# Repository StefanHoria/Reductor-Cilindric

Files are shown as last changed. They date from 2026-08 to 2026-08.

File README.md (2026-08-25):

# Single-Stage Helical Gear Reducer — RCil H

**Year project — Machine Elements (Organe de Mașini)**
Transilvania University of Brașov · Faculty of Mechanical Engineering
Department of Automotive and Transport Engineering · 2026

The complete design of a single-stage speed reducer with a helical cylindrical gear pair and a
horizontal shaft plane (the **RCil H** variant): from the design brief and the analytical
calculations, through 3D modelling in CATIA V5 and verification in MDESIGN, to the assembly drawing
and the detail drawings.

| | |
|---|---|
| **Author** | Horia-Eusebiu ȘTEFAN — Robotics programme, group 4LF832 |
| **Supervisors** | Prof. dr. eng. Gheorghe MOGAN · Dr. eng. Eugen BUTILĂ · Eng. Diana BUZDUGAN |
| **Software** | CATIA V5 (3D modelling, drawings), MDESIGN 2020 (shaft verification) |
| **Documentation** | [Technical report (PDF, 47 pages, Romanian)](docs/Memoriu-Tehnic-Stefan-Horia-Eusebiu.pdf) |

> 🇷🇴 Documentul în limba română: [README.ro.md](README.ro.md)

<p align="center">
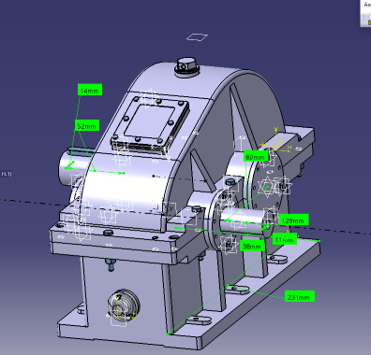
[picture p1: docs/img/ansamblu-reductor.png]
RCil H reducer — general assembly in CATIA V5
  
  <br>
  <sub><i>General assembly of the RCil H reducer on its test-bench frame, modelled in CATIA V5.</i></sub>
</p>

---

## 1. Design brief

| Parameter | Symbol | Value |
|---|---|---|
| Input power | `P_i` | 17.5 kW |
| Input speed | `n_i` | 3000 rpm |
| Transmission ratio | `i_R` | 3 |
| Required service life | `L_h imp` | 12,000 hours |
| Shaft plane | `PA` | Horizontal (H) |
| Number of pinion teeth | `z_1` | 19 |

**Operating conditions:** vehicle lift or brake test bench; alternating external load with shocks;
driven by a squirrel-cage asynchronous electric motor; noise level max. 25 dB; environment
−20…60 °C, humidity max. 30 g/m³.

**Construction constraints:** input and output on opposite sides, solid output shaft.

---

## 2. Kinetostatic parameters

| Shaft | Power | Speed | Torque |
|---|---|---|---|
| Input (A1) | `P_1` = 17.5 kW | `n_1` = 3000 rpm | `M_t1` = 55,704 Nmm |
| Output (A2) | `P_2` = 16.62 kW | `n_2` = 1000 rpm | `M_t2` = 158,756 Nmm |

Assumed gear efficiency: `η` = 0.95.
Tooth counts: `z_1` = 19, `z_2` = 57 → recalculated ratio `u` = 3, deviation from `i_R` = **0 %**.

---

## 3. The helical gear pair

<p align="center">
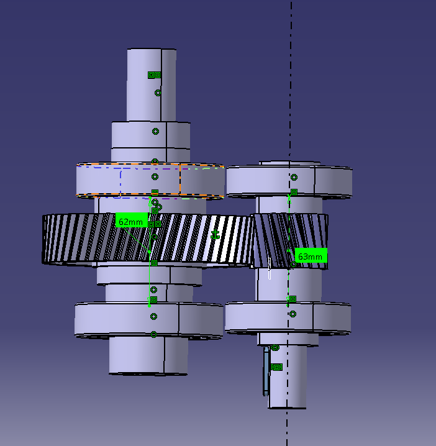
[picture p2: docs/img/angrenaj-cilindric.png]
Helical gear pair in mesh
  
  <br>
  <sub><i>The gear pair in mesh: pinion <code>z<sub>1</sub></code> = 19 and wheel <code>z<sub>2</sub></code> = 57,
  helix angle &beta; = 14&deg;, centre distance <code>a<sub>w</sub></code> = 80 mm.</i></sub>
</p>

### Material and heat treatment

Since `M_t1` = 55,704 Nmm > 30,000…40,000 Nmm, a **case-hardening steel, 20TiMnCr12**, was adopted
for both wheels.

| `σ_c` | `σ_r` | Treatment | Flank hardness | Core hardness | `σ_Hlim` | `σ_Flim` |
|---|---|---|---|---|---|---|
| 850 MPa | 1100 MPa | Carburising | 60 HRC | 340 HB | 1530 MPa | 430 MPa |

Manufacturing: milling before carburising, grinding after quenching and tempering.

### Preliminary sizing and geometry

Calculated transverse module: `m_c` = max(`m_H`, `m_F`) = max(1.89 ; 1.82) = **1.89 mm** → contact
stress is the governing criterion.

| Parameter | Relation | Value |
|---|---|---|
| Normal module (standardised) | `m_n` | 2 mm |
| Transverse module | `m = m_n / cos β` | 1.889 mm |
| Helix angle | `β` | 14° |
| Pinion reference diameter | `d_1 = m·z_1` | 35.9 mm |
| Wheel reference diameter | `d_2 = m·z_2` | 107.673 mm |
| Reference centre distance | `a` | 78.32 mm |
| **Standardised centre distance** | `a_w` | **80 mm** |
| Wheel face width | `b_2` | 27 mm |
| Pinion face width | `b_1 = b_2 + 4…6` | 31 mm |

Standardisation constraint `−0.5·m_n < a_w − a ≤ m_n` → `−1 < 1.68 ≤ 2` ✔

### Profile shift (PLUS gearing)

To achieve the required centre distance together with improved contact and bending strength:

| `x_n1` | `x_n2` | `x_ns` | `α` (transverse pressure) | `α_w` (transverse working) |
|---|---|---|---|---|
| +0.4711 | +0.4278 | 0.899 | 20.5617° | 23.561° |

Tooth tip thickness check (measured on the CATIA model):
`s_1` = 0.433 mm, `s_2` = 0.973 mm > (0.3…0.45)·`m_n`/2 ✔

### Contact continuity

Transverse contact ratio, obtained by measurement on the CATIA simulation model:
`ε_αm` = (T₁B − T₁A) / `p_b` = (12.884 − 4.589) / 6.043 = **1.372**
against the calculated value `ε_α` = **1.381** → deviation **−0.65 %** ✔

### Manufacturing and assembly

| | |
|---|---|
| Accuracy grade / fit | 8 / B, backlash tolerance type *b* |
| Final machining process | Careful milling and slotting |
| Surface roughness | flank `Ra` = 0.8 μm · root fillet `Ra` = 1.6 μm |
| Lubricant | TIN 300 EP transmission oil |
| Minimum normal backlash | `j_n min` = 87 μm |
| Radial runout tolerances | `F_r` = 45 μm (pinion) · 63 μm (wheel) |
| Span measurement | 19.85 ⁻⁰·¹ ⁻⁰·¹⁶ over 3 teeth (pinion) · 66.28 ⁻⁰·¹⁸ ⁻⁰·²⁸ over 9 teeth (wheel) |
| Centre distance limit deviations | `f_a` = ±70 μm |

### Gear mesh forces

| `F_t` (tangential) | `F_r` (radial) | `F_a` (axial) |
|---|---|---|
| 2785.2 N | 1213.94 N | 694.43 N |

---

## 4. Shafts, bearings and keys

<table>
<tr>
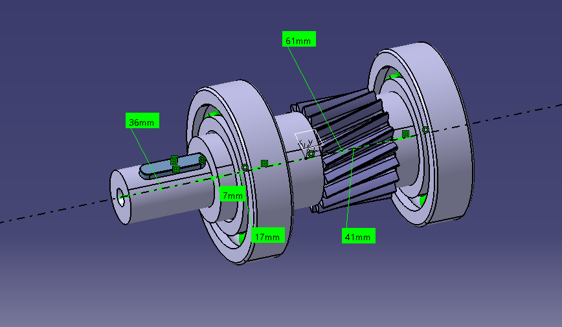
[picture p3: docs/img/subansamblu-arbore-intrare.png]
Input shaft subassembly
<td width="50%"></td>
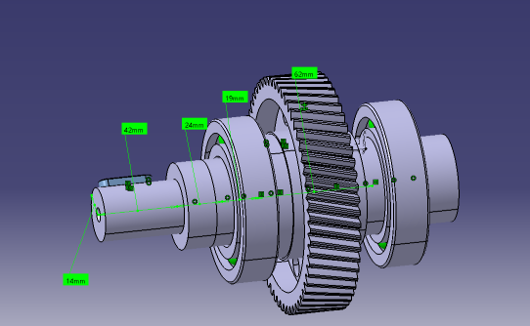
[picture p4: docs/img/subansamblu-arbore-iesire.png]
Output shaft subassembly
<td width="50%"></td>
</tr>
<tr>
<td align="center"><sub><b>Input shaft (A1)</b> — integral pinion, 6205 bearings, &#8960;22 &times; 36 mm shaft end</sub></td>
<td align="center"><sub><b>Output shaft (A2)</b> — gear wheel, 6213 bearings, &#8960;28 &times; 42 mm shaft end</sub></td>
</tr>
</table>

### Shafts

| | Input shaft (A1) | Output shaft (A2) |
|---|---|---|
| Material | 20TiMnCr12 (integral with the pinion) | C60 |
| Treatment | Carburised, 55…63 HRC | Quenched and tempered, 200…300 HB |
| `σ_c` / `σ_r` | 850 / 1100 MPa | 720 / 420 MPa |
| Torque | 55,704 Nmm | 158,756 Nmm |
| Allowable `τ_at` | 25 MPa | 35 MPa |
| Calculated diameter | 22.47 mm | 28.48 mm |
| **Standardised shaft end** | **⌀22 × 36 mm** | **⌀28 × 42 mm** |

### Bearings

Given moderate radial and small axial loads, **deep groove ball bearings** were adopted.

| Shaft | Designation | `d` | `D` | `B` | `C` |
|---|---|---|---|---|---|
| Input | 6205 | 35 mm | 72 mm | 17 mm | 25,500 N |
| Output | 6213 | 45 mm | 85 mm | 19 mm | 31,000 N |

Diameter of the seat under the gear wheel: `d_A2r` = `d_R2` + 10 = **55 mm**.

### Parallel key joints

Key material: **E295** (`σ_02` = 295 MPa, `σ_as` = 70…120 MPa, `τ_af` = 60…80 MPa).

| | Key I (type A) | Key II (type A) | Key III (type C) |
|---|---|---|---|
| `d` | 22 mm | 55 mm | 28 mm |
| `b × h` | 6 × 6 | 16 × 10 | 8 × 7 |
| Calculated `l_c` | 21.1 mm | 11.5 mm | 32.4 mm |
| Adopted `l` (STAS) | 28 mm | 45 mm | 50 mm |

For all three joints `l_c` < the available length → **a single key** is used in each case.

---

## 5. Verification

### Input shaft (MDESIGN 2020, *Shaft* module)

| Check | Criterion | Result |
|---|---|---|
| Combined stresses | `S_F min` ≥ 1.2 | **17.412** ✔ |
| Fatigue | `S_D min` ≥ 1.2 | **1.98** ✔ |
| Deflection at the gear | `y_x` ≤ 0.04…0.12 mm | ✔ |
| Maximum deflection | `y_max` ≤ 0.0452 mm | **0.035099 mm** ✔ |
| Maximum bearing tilt | `Θ_max` ≤ 0.97° | **0.0024505°** ✔ |
| Torsional vibration | `(0…n)` ≠ `(0.8…1.2)·f_0` | ✔ |
| Bending vibration | `(0…n)` ≠ `(0.8…1.2)·f_0` | ✔ |

Full report: [`mdesign/Raport-MDESIGN-Shaft-arbore-intrare.pdf`](mdesign/Raport-MDESIGN-Shaft-arbore-intrare.pdf)
Calculation source file: [`mdesign/Horia-verifdate.mdp.txt`](mdesign/Horia-verifdate.mdp.txt)

### Input shaft bearings (6205)

External forces: `F_rA` = 1871.70 N, `F_rB` = 2251.93 N, `F_a1` = ±694.42 N.
Influence factors (`f_0·F_a/C_0r` = 0.276, normal radial clearance CN): `e` = 0.28, `X` = 0.56,
`Y` = 1.58.

| Bearing | `F_a1/F_r` | Equivalent dynamic load |
|---|---|---|
| `L_A` | 0.371 > `e` | `P_A` = 2145.33 N |
| `L_B` | 0.308 > `e` | `P_B` = **2358.26 N** ← most heavily loaded |

Service life: `L_B` = (C/P_B)³ = **1265.8 million revolutions** → `L_h` = **7032.2 hours**.

---

## 6. Repository structure

```
.
├── cad/        the CATIA V5 models (54 files, names preserved so links do not break)
├── docs/       the technical report (PDF + DOCX)
│   └── img/    screenshots of the models and drawings, used in this README
├── date/       component and material lists, gear parameter table
└── mdesign/    the input shaft verification report
```

> [!IMPORTANT]
> All CATIA files are kept **flat, inside `cad/`, under their original names**. The `.CATProduct`
> and `.CATDrawing` files resolve their links to components by name and relative path — renaming
> them or moving them into subfolders breaks the assembly on open.

### CATIA models

**Assembly and subassemblies**

| File | Content |
|---|---|
| `Ansamblu H.CATProduct` | General assembly of the RCil H reducer |
| `Subansamblu arbore de intrare.CATProduct` | Pinion shaft + 6205 bearings + covers + seal |
| `Subansamblu arbore de iesire.CATProduct` | Output shaft + wheel + 6213 bearings + spacer |
| `Subansamblue angrenaj.CATProduct` | The complete helical gear pair |
| `Subansamblu Carcasa Inferioara.CATProduct` | Lower housing with accessories |
| `Subansamblu Carcasa Superioara.CATProduct` | Upper housing with sight glass, breather, inspection cover |
| `Model Cinematic RCil.CATProduct` | Model for the kinematic simulation of the mechanism |
| `Test carcase.CATProduct` | Fit check between the two housing halves |

**Meshing studies** (chapter 3 of the report)

| File | Content |
|---|---|
| `CATPart.3.3.3.2.1 Model dinti in angrenare.CATPart` | Tooth profiles of the **unshifted** wheels |
| `CATPart.3.3.3.2.1 Model dinti in angrenare deplasat.CATPart` | Gear pair with **profile-shifted** teeth (`x_n1` = +0.4711) |
| `CATPart.3.3.3.2.2 Model pentru simulare si verificare angrenare.CATPart` | Simulation and verification of meshing continuity |

**Main parts**

`CATPart.5.1.3 Arbore cu pinion cilindric` (pinion shaft) ·
`CAtPart.5.1.4 Arbore cu roata cilindrica` (wheel shaft) ·
`CATPart.9.5 Arbore de iesire` (output shaft) · `CATPart.9.1 Coroana pinion cilindric` (pinion rim) ·
`CATPart.9.4 Coroana roata cilindrica` (wheel rim) ·
`CATPart.11.1.1.1 Generare Carcasa inferioara H` (lower housing) ·
`CATPart.11.1.2.1 Generare Carcasa superioara H` (upper housing)

**Sealing, accessories and fasteners**

Bearing covers (1–4) · rotary seals · flat and cover gaskets · breather plug · drain plug · oil
level sight glass · inspection cover · spacer · parallel keys · locating pin · Grower washers ·
ISO 4017 / 4018 bolts and ISO 4032 nuts.

### Drawings

| File | Content |
|---|---|
| `Ansamblu HH.CATDrawing` | Assembly drawing of the reducer |
| `Desen de executie Arbore de intrare cu pinion cilindric.CATDrawing` | Detail drawing — pinion shaft |
| `Desen de executie Roata dintata cilindrica.CATDrawing` | Detail drawing — gear wheel |
| `Desen de executie arbore de iesire.CATDrawing` | Detail drawing — output shaft |
| `Format si chenar desen de ansamblu.CATDrawing` | Sheet format and border used |

<p align="center">
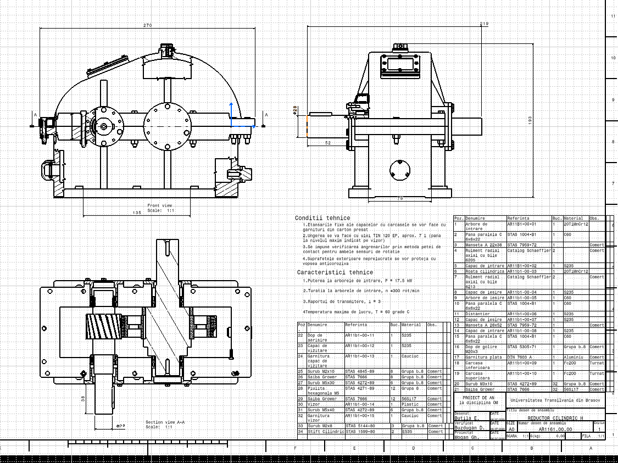
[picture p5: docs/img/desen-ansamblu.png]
Assembly drawing of the reducer
  
  <br>
  <sub><i>Assembly drawing — views, sections, technical conditions and the 34-item bill of materials.</i></sub>
</p>

<p align="center">
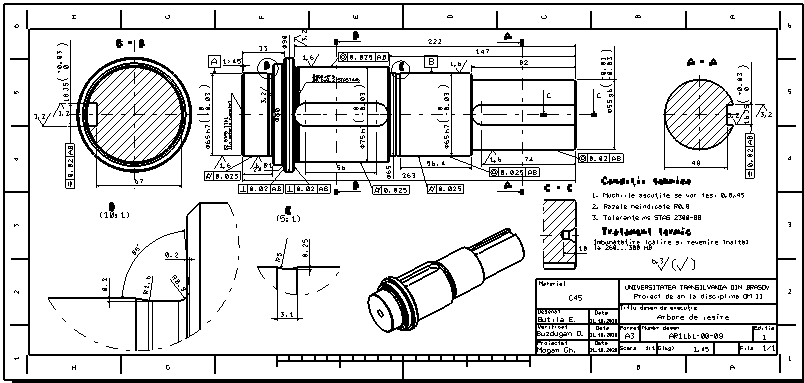
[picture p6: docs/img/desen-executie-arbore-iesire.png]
Detail drawing of the output shaft
  
  <br>
  <sub><i>Detail drawing of the output shaft (C45): dimensions, tolerances, geometric tolerances,
  surface roughness and heat treatment.</i></sub>
</p>

### Data

| File | Content |
|---|---|
| [`date/lista-componente.csv`](date/lista-componente.csv) | Bill of materials (34 items) for the assembly drawing |
| `date/lista-materiale.xls` | Material list |
| [`date/tabel-parametri-danturi-pinion.csv`](date/tabel-parametri-danturi-pinion.csv) | Gear parameter table for the pinion detail drawing |

---

## 7. Opening the files

1. **CATIA V5** (R2019 or newer) — clone the repository and open `cad/Ansamblu H.CATProduct`,
   keeping all files in the same folder.
2. **MDESIGN 2020 Second Edition**, *Shaft* module v18.0.13e — load
   `mdesign/Horia-verifdate.mdp.txt` (a UTF-16 XML file holding the calculation parameters).
3. To read the work without any licences, the PDF technical report contains screenshots of all
   models, diagrams and drawings.

```bash
git clone https://github.com/StefanHoria/Reductor-Cilindric.git
```

---

## 8. Notes on the documentation

Recorded for transparency, without altering the values in the original technical report:

- **Ch. 13 — shaft verification in MDESIGN**: the text partly carries over the values from the
  worked example in the course guide (`M_t1` = 312,071 Nmm, `n` = 625 rpm, `F_t` = 8770.6 N, steel
  18MoMnNi13) instead of this project's own data (`M_t1` = 55,704 Nmm, `n_1` = 3000 rpm,
  `F_t` = 2785.2 N, 20TiMnCr12). The reported safety factors still leave a comfortable margin.
- **Ch. 14 — bearing verification**: the calculated life `L_h` = 7032.2 hours is compared in the
  text against 11,787.94 hours, and the inequality as written (`7032.2 > 11,787.94`) does not hold
  numerically. Against the brief's required life of `L_h imp` = 12,000 hours, the result indicates
  that bearing `L_B` on the input shaft needs a higher dynamic capacity.
- Ch. 6.5 mentions `m_n` = 2.5 mm in the minimum-backlash relation and a centre distance of 180 mm
  in the tolerance customisation, whereas the rest of the project uses `m_n` = 2 mm and
  `a_w` = 80 mm.

---

## 9. References

1. Jula, A. et al. — *Organe de mașini*, vol. I, II. University of Brașov, 1986, 1989.
2. Mogan, Gh. et al. — *Organe de mașini. Teorie – Proiectare – Aplicații*. Transilvania University of Brașov Press, 2012.
3. Moldovean, Gh. et al. — *Angrenaje cilindrice și conice. Calcul și construcție*. LuxLibris, Brașov, 2001.
4. Moldovean, Gh. et al. — *Angrenaje cilindrice și conice. Metodici de proiectare*. LuxLibris, Brașov, 2002.
5. Rădulescu, C. — *Organe de mașini*, vol. I, II, III. Transilvania University of Brașov, 1985.
6. \*\*\* — *Culegere de norme și extrase din standarde pentru proiectarea elementelor componente ale mașinilor*, vol. I, II. University of Brașov, 1984.

---

## License

Academic work published for portfolio purposes. The content may be read and cited with attribution
to the author; it is not intended for commercial reuse or for submission as someone else's own work.

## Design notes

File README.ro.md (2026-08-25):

# Reductor cilindric cu o treaptă — RCil H

**Proiect de an la disciplina Organe de Mașini**
Universitatea Transilvania din Brașov · Facultatea de Inginerie Mecanică
Departamentul Autovehicule și Transporturi · 2026

Proiectarea completă a unui reductor de turație cu o treaptă, cu angrenaj cilindric cu dantură
înclinată și plan orizontal al axelor (varianta **RCil H**): de la tema de proiectare și calculul
analitic, prin modelarea 3D în CATIA V5 și verificarea în MDESIGN, până la desenul de ansamblu și
desenele de execuție.

| | |
|---|---|
| **Autor** | Horia-Eusebiu ȘTEFAN — Programul de studii Robotică, grupa 4LF832 |
| **Coordonatori** | Prof. univ. dr. ing. Gheorghe MOGAN · Dr. ing. Eugen BUTILĂ · Drd. ing. Diana BUZDUGAN |
| **Software** | CATIA V5 (modelare 3D, desene), MDESIGN 2020 (verificare arbori) |
| **Documentație** | [Memoriu tehnic (PDF, 47 pagini)](docs/Memoriu-Tehnic-Stefan-Horia-Eusebiu.pdf) |

> 🇬🇧 English version: [README.md](README.md)

<p align="center">
  Reductorul RCil H — ansamblul general in CATIA V5
  <br>
  <sub><i>Ansamblul general al reductorului RCil H pe cadrul suport, modelat in CATIA V5.</i></sub>
</p>

---

## 1. Tema de proiectare

| Parametru | Simbol | Valoare |
|---|---|---|
| Puterea la intrare | `P_i` | 17,5 kW |
| Turația la intrare | `n_i` | 3000 rot/min |
| Raportul de transmitere | `i_R` | 3 |
| Durata de funcționare impusă | `L_h imp` | 12 000 ore |
| Planul axelor | `PA` | Orizontal (H) |
| Numărul de dinți ai pinionului | `z_1` | 19 |

**Condiții de funcționare:** utilaj de tip elevator auto sau stand de testare frâne; încărcare
exterioară alternativă cu șocuri; acționare cu motor electric asincron cu rotorul în scurtcircuit;
nivel de zgomot max. 25 dB; mediu −20…60 °C, umiditate max. 30 g/m³.

**Condiții constructive:** intrare și ieșire pe părți opuse, arbore de ieșire plin.

---

## 2. Parametri cinetostatici

| Arborele | Puterea | Turația | Momentul de torsiune |
|---|---|---|---|
| Intrare (A1) | `P_1` = 17,5 kW | `n_1` = 3000 rot/min | `M_t1` = 55 704 Nmm |
| Ieșire (A2) | `P_2` = 16,62 kW | `n_2` = 1000 rot/min | `M_t2` = 158 756 Nmm |

Randamentul angrenajului cilindric considerat: `η` = 0,95.
Numere de dinți: `z_1` = 19, `z_2` = 57 → raport recalculat `u` = 3, abatere față de `i_R` = **0 %**.

---

## 3. Angrenajul cilindric

<p align="center">
  Angrenajul cilindric cu dantura inclinata
  <br>
  <sub><i>Angrenajul in functionare: pinionul <code>z<sub>1</sub></code> = 19 si roata <code>z<sub>2</sub></code> = 57,
  unghi de inclinare &beta; = 14&deg;, distanta dintre axe <code>a<sub>w</sub></code> = 80 mm.</i></sub>
</p>

### Material și tratament termic

Deoarece `M_t1` = 55 704 Nmm > 30 000…40 000 Nmm, s-a adoptat pentru ambele roți un **oțel de
cementare, 20TiMnCr12**.

| `σ_c` | `σ_r` | Tratament | Duritate flanc | Duritate miez | `σ_Hlim` | `σ_Flim` |
|---|---|---|---|---|---|---|
| 850 MPa | 1100 MPa | Cementare | 60 HRC | 340 HB | 1530 MPa | 430 MPa |

Prelucrare: frezare înainte de cementare, rectificare după călire și revenire.

### Predimensionare și geometrie

Modulul frontal calculat: `m_c` = max(`m_H`, `m_F`) = max(1,89 ; 1,82) = **1,89 mm** → solicitarea
de contact este solicitarea principală.

| Parametru | Relație | Valoare |
|---|---|---|
| Modulul normal (standardizat) | `m_n` | 2 mm |
| Modulul frontal | `m = m_n / cos β` | 1,889 mm |
| Unghiul de înclinare a danturii | `β` | 14° |
| Diametrul de divizare pinion | `d_1 = m·z_1` | 35,9 mm |
| Diametrul de divizare roată | `d_2 = m·z_2` | 107,673 mm |
| Distanța dintre axe de referință | `a` | 78,32 mm |
| **Distanța dintre axe standardizată** | `a_w` | **80 mm** |
| Lățimea danturii roții | `b_2` | 27 mm |
| Lățimea danturii pinionului | `b_1 = b_2 + 4…6` | 31 mm |

Restricția de standardizare `−0,5·m_n < a_w − a ≤ m_n` → `−1 < 1,68 ≤ 2` ✔

### Deplasări de profil (angrenaj PLUS)

Pentru a asigura distanța dintre axe impusă și rezistențe mărite la contact și încovoiere:

| `x_n1` | `x_n2` | `x_ns` | `α` (presiune frontal) | `α_w` (angrenare frontal) |
|---|---|---|---|---|
| +0,4711 | +0,4278 | 0,899 | 20,5617° | 23,561° |

Verificarea ascuțirii dinților (măsurată pe modelul CATIA):
`s_1` = 0,433 mm, `s_2` = 0,973 mm > (0,3…0,45)·`m_n`/2 ✔

### Continuitatea angrenării

Gradul de acoperire frontal, obținut prin măsurare pe modelul CATIA de simulare:
`ε_αm` = (T₁B − T₁A) / `p_b` = (12,884 − 4,589) / 6,043 = **1,372**
față de valoarea calculată `ε_α` = **1,381** → abatere **−0,65 %** ✔

### Execuție și montaj

| | |
|---|---|
| Treapta de precizie / ajustaj | 8 / B, toleranța jocului tip *b* |
| Procedeu de prelucrare final | Frezare îngrijită și mortezare |
| Rugozități | flanc `Ra` = 0,8 μm · racordare `Ra` = 1,6 μm |
| Lubrifiant | ulei de transmisii TIN 300 EP |
| Joc minim normal | `j_n min` = 87 μm |
| Toleranțe bătaie radială | `F_r` = 45 μm (pinion) · 63 μm (roată) |
| Cota peste dinți | 19,85 ⁻⁰·¹ ⁻⁰·¹⁶ peste 3 dinți (pinion) · 66,28 ⁻⁰·¹⁸ ⁻⁰·²⁸ peste 9 dinți (roată) |
| Abateri limită distanță între axe | `f_a` = ±70 μm |

### Forțe în angrenaj

| `F_t` (tangențială) | `F_r` (radială) | `F_a` (axială) |
|---|---|---|
| 2785,2 N | 1213,94 N | 694,43 N |

---

## 4. Arbori, rulmenți și pene

<table>
<tr>
<td width="50%">Subansamblul arborelui de intrare</td>
<td width="50%">Subansamblul arborelui de iesire</td>
</tr>
<tr>
<td align="center"><sub><b>Arborele de intrare (A1)</b> — pinion corp comun, rulmenti 6205, capat &#8960;22 &times; 36 mm</sub></td>
<td align="center"><sub><b>Arborele de iesire (A2)</b> — roata dintata, rulmenti 6213, capat &#8960;28 &times; 42 mm</sub></td>
</tr>
</table>

### Arbori

| | Arbore de intrare (A1) | Arbore de ieșire (A2) |
|---|---|---|
| Material | 20TiMnCr12 (corp comun cu pinionul) | C60 |
| Tratament | Cementare, 55…63 HRC | Îmbunătățire, 200…300 HB |
| `σ_c` / `σ_r` | 850 / 1100 MPa | 720 / 420 MPa |
| Moment de torsiune | 55 704 Nmm | 158 756 Nmm |
| `τ_at` admisibil | 25 MPa | 35 MPa |
| Diametru calculat | 22,47 mm | 28,48 mm |
| **Cap de arbore standardizat** | **⌀22 × 36 mm** | **⌀28 × 42 mm** |

### Rulmenți

Din considerente de încărcare cu forțe radiale medii și axiale mici s-au adoptat **rulmenți radiali
cu bile**.

| Arborele | Simbol | `d` | `D` | `B` | `C` |
|---|---|---|---|---|---|
| De intrare | 6205 | 35 mm | 72 mm | 17 mm | 25 500 N |
| De ieșire | 6213 | 45 mm | 85 mm | 19 mm | 31 000 N |

Diametrul tronsonului de sub roata cilindrică: `d_A2r` = `d_R2` + 10 = **55 mm**.

### Asamblări cu pene paralele

Material pene: **E295** (`σ_02` = 295 MPa, `σ_as` = 70…120 MPa, `τ_af` = 60…80 MPa).

| | Pana I (tip A) | Pana II (tip A) | Pana III (tip C) |
|---|---|---|---|
| `d` | 22 mm | 55 mm | 28 mm |
| `b × h` | 6 × 6 | 16 × 10 | 8 × 7 |
| `l_c` calculat | 21,1 mm | 11,5 mm | 32,4 mm |
| `l` adoptat (STAS) | 28 mm | 45 mm | 50 mm |

Pentru toate cele trei asamblări `l_c` < lungimea disponibilă → se adoptă câte **o singură pană**.

---

## 5. Verificări

### Arborele de intrare (MDESIGN 2020, modul *Shaft*)

| Verificarea | Criteriu | Rezultat |
|---|---|---|
| Solicitări compuse | `S_F min` ≥ 1,2 | **17,412** ✔ |
| Oboseală | `S_D min` ≥ 1,2 | **1,98** ✔ |
| Săgeată în zona angrenajului | `y_x` ≤ 0,04…0,12 mm | ✔ |
| Săgeată maximă | `y_max` ≤ 0,0452 mm | **0,035099 mm** ✔ |
| Rotiri maxime în lagăre | `Θ_max` ≤ 0,97° | **0,0024505°** ✔ |
| Vibrații torsionale | `(0…n)` ≠ `(0,8…1,2)·f_0` | ✔ |
| Vibrații flexionale | `(0…n)` ≠ `(0,8…1,2)·f_0` | ✔ |

Raportul complet: [`mdesign/Raport-MDESIGN-Shaft-arbore-intrare.pdf`](mdesign/Raport-MDESIGN-Shaft-arbore-intrare.pdf)
Fișierul sursă de calcul: [`mdesign/Horia-verifdate.mdp.txt`](mdesign/Horia-verifdate.mdp.txt)

### Rulmenții arborelui de intrare (6205)

Forțe exterioare: `F_rA` = 1871,70 N, `F_rB` = 2251,93 N, `F_a1` = ±694,42 N.
Factori de influență (`f_0·F_a/C_0r` = 0,276, joc radial normal CN): `e` = 0,28, `X` = 0,56, `Y` = 1,58.

| Lagăr | `F_a1/F_r` | Sarcina dinamică echivalentă |
|---|---|---|
| `L_A` | 0,371 > `e` | `P_A` = 2145,33 N |
| `L_B` | 0,308 > `e` | `P_B` = **2358,26 N** ← cel mai încărcat |

Durabilitate: `L_B` = (C/P_B)³ = **1265,8 milioane de rotații** → `L_h` = **7032,2 ore**.

---

## 6. Structura repository-ului

```
.
├── cad/        modelele CATIA V5 (54 fișiere, nume păstrate pentru a nu rupe linkurile)
├── docs/       memoriul tehnic (PDF + DOCX)
│   └── img/    capturi ale modelelor și desenelor, folosite în acest README
├── date/       liste de componente și materiale, tabelul de parametri ai danturii
└── mdesign/    raportul de verificare a arborelui de intrare
```

> [!IMPORTANT]
> Toate fișierele CATIA sunt păstrate **plat, în `cad/`, cu numele originale**. Fișierele
> `.CATProduct` și `.CATDrawing` rezolvă legăturile către componente pe bază de nume și cale
> relativă — redenumirea sau mutarea lor în subfoldere rupe ansamblul la deschidere.

### Modele CATIA

**Ansamblu și subansamble**

| Fișier | Conținut |
|---|---|
| `Ansamblu H.CATProduct` | Ansamblul general al reductorului RCil H |
| `Subansamblu arbore de intrare.CATProduct` | Arbore-pinion + rulmenți 6205 + capace + manșetă |
| `Subansamblu arbore de iesire.CATProduct` | Arbore de ieșire + roată + rulmenți 6213 + distanțier |
| `Subansamblue angrenaj.CATProduct` | Angrenajul cilindric complet |
| `Subansamblu Carcasa Inferioara.CATProduct` | Carcasa inferioară cu accesorii |
| `Subansamblu Carcasa Superioara.CATProduct` | Carcasa superioară cu vizor, bușon, capac de vizitare |
| `Model Cinematic RCil.CATProduct` | Model pentru simularea cinematică a mecanismului |
| `Test carcase.CATProduct` | Verificare de potrivire a celor două carcase |

**Studii de angrenare** (cap. 3 din memoriu)

| Fișier | Conținut |
|---|---|
| `CATPart.3.3.3.2.1 Model dinti in angrenare.CATPart` | Profilele dinților roților **nedeplasate** |
| `CATPart.3.3.3.2.1 Model dinti in angrenare deplasat.CATPart` | Angrenajul cu danturi **deplasate** (`x_n1` = +0,4711) |
| `CATPart.3.3.3.2.2 Model pentru simulare si verificare angrenare.CATPart` | Simularea și verificarea continuității angrenării |

**Piese principale**

`CATPart.5.1.3 Arbore cu pinion cilindric` · `CAtPart.5.1.4 Arbore cu roata cilindrica` ·
`CATPart.9.5 Arbore de iesire` · `CATPart.9.1 Coroana pinion cilindric` ·
`CATPart.9.4 Coroana roata cilindrica` · `CATPart.11.1.1.1 Generare Carcasa inferioara H` ·
`CATPart.11.1.2.1 Generare Carcasa superioara H`

**Etanșare, accesorii și organe de asamblare**

Capace de rulment (1–4) · manșete de rotație · garnituri plate și de capac · bușon de aerisire ·
dop de golire · vizor de nivel ulei · capac de vizitare · distanțier · pene paralele · știft de
poziționare · șaibe Grower · șuruburi ISO 4017 / 4018 și piulițe ISO 4032.

### Desene

| Fișier | Conținut |
|---|---|
| `Ansamblu HH.CATDrawing` | Desenul de ansamblu al reductorului |
| `Desen de executie Arbore de intrare cu pinion cilindric.CATDrawing` | Desen de execuție |
| `Desen de executie Roata dintata cilindrica.CATDrawing` | Desen de execuție |
| `Desen de executie arbore de iesire.CATDrawing` | Desen de execuție |
| `Format si chenar desen de ansamblu.CATDrawing` | Formatul și chenarul folosit |

<p align="center">
  Desenul de ansamblu al reductorului
  <br>
  <sub><i>Desenul de ansamblu — vederi, sectiuni, conditii tehnice si tabelul de componenta cu 34 de pozitii.</i></sub>
</p>

<p align="center">
  Desenul de executie al arborelui de iesire
  <br>
  <sub><i>Desen de executie — arborele de iesire (C45): cote, tolerante dimensionale si geometrice,
  rugozitati si tratament termic.</i></sub>
</p>

### Date

| Fișier | Conținut |
|---|---|
| [`date/lista-componente.csv`](date/lista-componente.csv) | Tabelul de componență (34 poziții) al desenului de ansamblu |
| `date/lista-materiale.xls` | Lista de materiale |
| [`date/tabel-parametri-danturi-pinion.csv`](date/tabel-parametri-danturi-pinion.csv) | Tabelul de parametri ai danturii, pentru desenul de execuție al pinionului |

---

## 7. Cum se deschid fișierele

1. **CATIA V5** (R2019 sau mai nou) — clonează repository-ul și deschide `cad/Ansamblu H.CATProduct`
   păstrând toate fișierele în același folder.
2. **MDESIGN 2020 Second Edition**, modulul *Shaft* v18.0.13e — încarcă
   `mdesign/Horia-verifdate.mdp.txt` (fișier XML UTF-16 cu parametrii de calcul).
3. Pentru citire fără licențe, memoriul tehnic în PDF conține toate capturile de ecran ale
   modelelor, diagramelor și desenelor.

```bash
git clone https://github.com/StefanHoria/Reductor-Cilindric.git
```

---

## 8. Observații privind documentația

Notate pentru transparență, fără a modifica valorile din memoriul tehnic original:

- **Cap. 13 — verificarea arborelui în MDESIGN**: textul preia parțial valorile din exemplul-șablon
  al îndrumarului (`M_t1` = 312 071 Nmm, `n` = 625 rot/min, `F_t` = 8770,6 N, oțel 18MoMnNi13) în
  loc de datele proprii ale proiectului (`M_t1` = 55 704 Nmm, `n_1` = 3000 rot/min, `F_t` = 2785,2 N,
  20TiMnCr12). Coeficienții de siguranță raportați rămân cu marjă confortabilă.
- **Cap. 14 — verificarea rulmenților**: durabilitatea calculată `L_h` = 7032,2 ore este comparată
  în text cu 11 787,94 ore, iar inegalitatea scrisă (`7032,2 > 11 787,94`) nu se verifică numeric.
  Față de durata impusă prin temă, `L_h imp` = 12 000 ore, rezultatul indică necesitatea unui rulment
  cu capacitate dinamică mai mare pentru lagărul `L_B` al arborelui de intrare.
- Cap. 6.5 menționează `m_n` = 2,5 mm în relația jocului minim și o distanță între axe de 180 mm în
  personalizarea toleranțelor, în timp ce restul proiectului folosește `m_n` = 2 mm și `a_w` = 80 mm.

---

## 9. Bibliografie

1. Jula, A. ș.a. — *Organe de mașini*, vol. I, II. Universitatea din Brașov, 1986, 1989.
2. Mogan, Gh. ș.a. — *Organe de mașini. Teorie – Proiectare – Aplicații*. Ed. Universității Transilvania din Brașov, 2012.
3. Moldovean, Gh. ș.a. — *Angrenaje cilindrice și conice. Calcul și construcție*. Ed. LuxLibris, Brașov, 2001.
4. Moldovean, Gh. ș.a. — *Angrenaje cilindrice și conice. Metodici de proiectare*. Ed. LuxLibris, Brașov, 2002.
5. Rădulescu, C. — *Organe de mașini*, vol. I, II, III. Universitatea Transilvania din Brașov, 1985.
6. \*\*\* — *Culegere de norme și extrase din standarde pentru proiectarea elementelor componente ale mașinilor*, vol. I, II. Universitatea din Brașov, 1984.

---

## Licență

Lucrare academică publicată în scop de portofoliu. Conținutul poate fi consultat și citat cu
indicarea autorului; nu este destinat reutilizării comerciale sau depunerii ca lucrare proprie.

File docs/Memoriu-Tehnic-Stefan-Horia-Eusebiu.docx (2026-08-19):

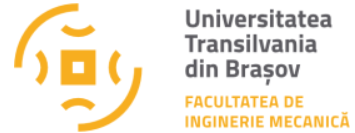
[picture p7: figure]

Departamentul Autovehicule și Transporturi

Disciplina Organe de Maşini

PROIECT DE AN LA DISCIPLINA

Organe de Maşini

Autor: Student Horia – Eusebiu STEFAN

Programul de studii: Robotică

Grupa: 4LF832

Coordonatori: Prof. univ. dr. ing. Gheorghe MOGAN

Dr. ing. Eugen BUTILĂ

Drd. ing. Diana BUZDUGAN

2026

| UNIVERSITATEA TRANSILVANIA DIN BRAŞOV FACULTATEA DE INGINERIE MECANICĂ Disciplina Organe de Maşini

MEMORIU TEHNIC

Autor: Student Horia – Eusebiu STEFAN

Grupa: 4LF832

Coordonatori: Prof. univ. dr. ing. Gheorghe MOGAN

Dr. ing. Eugen BUTILĂ

Drd. ing. Diana BUZDUGAN

2026

ANEXE (aplcaţii în CATIA)

1. Modelul dinților roților nedeplasate în angrenare
2. Modelul angrenajului cilindric cu danturi deplasate şi verificarea continuității angrenării
3. Model pentru simularea cinematică a mecanismului
4. Modelul 3D al reductorului
5. Desenul de ansamblu al reductorului
6. Desene de execuţie

# PREFAȚĂ

Disciplina Organe de mașini este prima disciplină cu caracter aplicativ din programul de pregătire a studenților de la programele de studiu cu profil mecanic prin faptul că implică activități de proiect cu tematici concrete, care se finalizează cu documentație tehnică scrisă și grafică (desen de ansamblu și desene de execuție).

Scopul proiectului la disciplina Organe de maşini este să dezvolte abilităţile practice ale studenţilor de proiectare bazat, pe de-o parte, pe implementarea cunoştinţelor, cu precădere, de Mecanică, Rezistenţa materialelor și Tehnologia materialelor, dobândite în decursul anilor I şi II, pentu calcule de dimensionare şi/sau de verificare, și pe de altă parte, de Desen tehnic, Infografică și Programare pentru reprezentarea grafică a soluțiilor calculate în documente de execuție, montaj, uilizare și chiar de reciclare a viitorului produs. Astfel, aceștia sunt puși în fața faptului de a soluționa în mod independent o lucrare de proiectare, pe baza algoritmilor, metodelor specifice şi pachetelor software avansate din domeniu.

Ca suport pentru derularea activității la proiectul de an la disciplina Organe de maşini s-a utilizat pezentul Îndrumar de proiectare care a fost structurat astfel încât să înlesnească activitatea de instruire a studenților atât pentru a dobândi cunoștințe teoretice cât și abilități practice de lucru cu pachete performante software. Pentru a răspunde, în totalitate, cerințelor impuse prin tema de proiectare este necesar să se urmărească atât etapele de calcul propriu-zis structurate algoritmizat cât și identificarea soluțiilor constructive adecvate, ținând cont și de normle și standardele actuale.

Tematica proiectului privind proiectarea reductoarelor cilindrice s-a adoptat, pe de-o parte, pentru a acoperi aplicativ a cât mai multe cunoștințe prezentate teoretic la curs și, pe de altă parte, ca abilitățile dobăndite de studenți în urma finalizării acestuia să fie suport pentru proiectele ulterioare în cadrul disciplinelor de specialitate.

Deoarece, în ultimul timp, utilizarea calculatorului în activitatea de proiectare s-a consacrat prin apariția de pachete software de calcul, de analiză și de reprezentare grafică laborioase cu interfețe utilizator prietenoase, structura acestei lucrări a fost concepută pentru integrarea în toate etapele de rezolvare a tematicii propuse a tehnologiilor informatice actuale. Această dezvoltare a fost favorizată și de suportul susținut al conducerilor departamentului Autovehicule și Transporturi, facultății de Inginerie Mecanică și Universității Transilvania din Brașov, pe de-o parte, de a achizițione de pachete software performante, chiar și pentru activitatea didactică la nivel de licență și, pe de altă parte, de a asigura săli dotate cu calculatoare performante la nivelul calculator-student. Astfel, în cadrul activităților de proiect și laboartor la disciplina Organe de mașini, și nu numai, s-au dezvoltat și implementat aplicații practice bazate pe pachete software performante actuale (MDESIGN, CATIA, ANSYS). Pentru a facilita lucrul studențiilor cu aceste softuri s-au conceput aplicații de tip ghid care să permită parcurgerea logică a etapelor cu luarea de decizii pe parcurs fără a elimina contribuțiile proprii atât la nivel de concept cât și de detaliu.

Pentru accesarea rapidă a informațiilor necesare privind desfășurarea calculelor precum și pentru documentare privind soluțiile constructive (inclusiv, cele standardizate) și elaborare a documentației finale (memoriu tehnic, desene de anasamblu și de execuție) s-au folosit documente suport integrate într-un algoritm de proiectare predestinat, dar și general, care acoperă mai multe variante de proiectare. Această structurare permite rezolvarea proiectului de fiecare student prin personalizări proprii, favorizat fiind și de exemplele aplicative accesibile ca documente distincte în îndrumarul de proiectare.

Autorul,

# 1. ASPECTE GENERALE ŞI TEMA DE PROIECTARE

1.1 Descriere generală a produsului

Reductorul de turaţie este un sistem mecanic demontabil, cu mişcări relative între elemente active (roţi dinţate, arbori, rulmanți) care are ca parametri de intrare, puterea (momentul de torsiune) şi turaţia (viteza unghiulară) arborelui de intrare şi, ca parametri de ieşire, puterea (momentul de torsiune) şi turaţia (viteza unghiulară) arborelui de ieşire.

Pe lângă funcţia principală de transmitere a momentului de torsiune şi mişcării de rotaţie prin angrenajele cu roti dinţate cilindrice se urmăreşte şi îndeplinirea următoarelor funcţii auxiliare: de construcție modulară, de respectarea prevederilor de interschimbabilitate cerute de standardele din domeniu; de respectarea condiţiilor de protecţie a omului şi mediului etc.

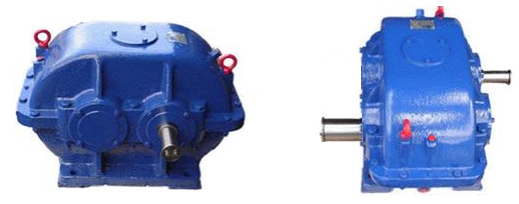
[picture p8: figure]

1.2 Obiective și date de proiectare

Obiectivele proiectului

Obiectivul principal

Dobândirea şi dezvoltarea de către studenți de cunoștințe şi abilităţi pentru identificarea, calculul şi proiectarea formei elementelor componente ale transmisiilor mecanice, cu precădere reductoare cilindrice, în vederea execuţiei şi montajului acestora.

Obiective specifice

- dezvoltarea de cunoştinţe fundamentale privind calculul şi proiectarea elementelor transmisiilor mecanice, inclusiv aspecte privind alegerea materialelor şi a tehnologiile de execuţie şi montaj;
- calculul elementelor şi subansamblelor specializate ale transmisiilor mecanice de tip reductor de turaţie cilindric (angrenaj, roţi dinţate, arbori, rulmenţi etc.);
- dezvoltarea de cunoștințe de identificare şi proiectare a formelor elementelor şi subansamblelor transmisiilor mecanice, cu precădere a reductoarelor cilindrice;
- dezvoltarea de abilităţi practice de utilizare a pachetelor performante de calcul (MDESIGN și ANSYS) şi pentru reprezentare grafică (CATIA);
- dezvoltarea de abilităţi practice de elaborare a documentaţiei grafice (modele 3D, desene de ansamblu şi de execuţie);
- dezvoltarea de abilităţi practice de elaborare a documentației scrise (memoriul tehnic).

Date de proiectare

Tema de proiectare a unui produs, de obicei, este lansată de către un beneficiar şi reprezintă o înşiruire de date, cerinţe şi condiţii tehnice care constituie caracteristicile şi performanţele impuse viitorului produs.

În tabelul următor se prezintă datele de proiectare impuse pentru o situaţie practică cerută, unde Pi [kW] reprezintă puterea la intrare, ni [rot/min] - turaţia la intrare, iR - raportul de transmitere al reductorului, L_h^(imp) [ore] - durata de funcţionare impusă, PA - planul axelor roţilor angrenajului cilindric: orizontal (H) sau vertical (V), z_1^(cil) - numărul de dinţi ai pinionului cilindric.

Pi [kW] | ni [rot/min] | iR | Lh imp [ore] | PA
17,5 | 3000 | 3 | 12000 | H | 19

Condiţii de funcţionare şi constructive

Condiţii de funcţionare:

- tipul maşinii (utilajului) în care se integrează: elevator auto sau stand testare frâne;
- tipul încărcării exterioare: alternativă cu şocuri;
- tipul motorului de acţionare: electric, asincron cu rotorul în scurtcircuit;
- nivel de vibraţii şi zgomot, max 25 dB;
- caracteristicile mediului în care funcţioneză: temperaura (- 20 … 60 oC), umiditate max 30 g/m³;

Condiţii constructive: intrarea și ieşirea pe părți opuse; arborele de ieşire plin.

Condiţii ecologice: utilizarea de materiale şi tehnologii eco, reciclarea materialelor, protecţia vieţii; volum minim; greutate minimă.

Domenii de utilizare

Reductorul de turaţie de proiectat se poate întegra în structurile unor maşini de ridicat şi transportat (de ex. elevatoare pentru ridicarea autoturismelor), instalații de tesatare (de ex. pentru frâne) etc.

2. SCHEMA STRUCTURALĂ ŞI PARAMETRI CINETOSTATICI

2.1 Schema structurală

Schema structurală funcțional-constructivă

În figură se prezintă schema structurală funcţional-constructivă generală a reductoarelor cilindrice cu o treptă. Din punct de vedere funcţional se evidenţiază următoare părți: angrenaj cilindric cu dantură înclinită; 1I – pinion cilindric; 2I – roată cilindică; A1 – arbore de intrare; A2 – arbore de ieşire; L_A^(A_1) - lagărul A al arborelui A1; L_B^(A_1) - lagărul B al arborelui A1.

Din punct de vedere constructiv, reductorul de turaţie formează un ansamblu compus din subansamble şi elemente constructive. Subansamblele sunt structuri independente, care se evidenţiază printr-un grup compact compus, în configuraţie minimală, din cel puţin două elemente constructive sau din alte subansamble şi elemente constructive, în interacţiune permanentă, formate ţinându-se cont, cu precădere, de tehnologiile de montaj, de întreţinere şi de exploatare.

În cazul reductoarelor cilindrice cu o treaptă se definesc următoarele subansamble: S_(A_1) - subansamblul arborelui de intrare, S_(A_2) - subansamblul arborelui de ieșire, și SC – subansambul carcasă care le susține pe primele două.

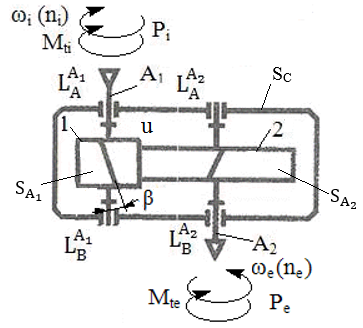
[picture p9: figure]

2.2 Parametri cinetostatici

Numere de dinţi şi raportul de angrenare

Considerând valorarea numărului de dinţi ai pinionului cilindric, z1 = z_1^(cil) se determină valoarea numărului de dinţi ai roţii cilindrice. În tabelul următor se prezintă sintetic aceste valori precum şi abaterea Ab a rapotului de angrenare recalculat faţă de cel de transmitere impus; această abatere respectă limita de max ± 2%.

z_1^I | z_2^I | u_(rec1) | i_R | Ab
19 | 57 | 3 | 3 | 0%

Puteri, turaţii şi momente de torsiune

Valorile puterilor, turațiilor și momentelor de torsiune la nivelul arborilor reductorului sunt:

Arborele | Puterea [kW] | Turaţia [rot/min] | Momentul de torsiune [Nmm]
Arborele intrare (A1) | P1 = 17,5 | n1 = 3000 | Mt1 = 55704
Arborele de ieşire (A2) | P2 =16,62 | n2 = 1000 | Mt2 = 158756

Obs. S-a considerat randamentul angrenajului cilindric, η = 0,95.

# 3. PREDIMENSIONAREA ANGRENAJULUI CILINDRIC

3.1 Alegerea oţelului roţilor dinţate, tratamentelor termice şi tehnologiilor

Alegerea tipului oţelului şi tratamentelor termice

Deoarece, Mti = 55704 Nmm > 30000...40000 Nmm, se adoptă pentru roţile angrenajului un oţel de cementare.

Alegerea oţelului, durităţilor şi rezistenţelor

Pentru ambele roţi dinţate se adoptă oţelul, 20TiMnCr12, (0,20% C, aliat cu Titan , Mangan, Crom 1,30%,) cu caracteristicile mecanice din tabel.

Oţelul | Limita de curgere, σc [MPa] | Rezistenţa la rupere, σr [MPa] | Tratamentul termic de bază | Durităţile flancurilor dinţilor roţilor | Durităţile zonelor interioare ale dinţilor | Tensiunea limită la contact, σHlim [MPa] | Tensiunea limită la încovoiere, σFlim [MPa]
20TiMnCr 12 | 850 | 1100 | Cementare | HRC = 60 | HB1,2 = 340 | 1530 | 430

Procedee de prelucrare a danturilor roților cilindrice

Corespunzător tipului oţelului şi tratamentului termic adoptate se impune prelucrarea prin frezare înainte de cementare şi prin rectificare după călire şi revenire.

3.2 Predimensionarea angrenajului cilindric

Determinarea modulului frontal al danturilor roților cilindrice

În figură se prezintă schema parametrilor principali de calcul a angrenajului cilindric în care se evidenţiază momentul de torsiune al pinionului (T1) şi parametri geometrici principali de calcul: diametrul de divizare al pinionului (d1), diametrul de divizare al roţii (d2), lăţimea danturii (b), distanţa dintre axe de referinţă (a), unghiul de înclinare a danturii (β).

Date de intrare

În tabelul următor sunt sintetizate valorile parametrilor de calcul cunoscuţi.

Denumirea parametrului | Simbolul | Valoarea | Unitatea de măsură
Raportul de angrenare | u | 3 | -
Numărul de dinţi al pinionului | z1 | 19 | -
Momentul de torsiune al pinionului | T1 | 55704 | Nmm
Turaţia pinionului conic | np | 3000 | rot/min
Durata de funcţionare impusă | Lh imp | 12000 | ore
Tensiunea limită la oboseala de contact, | σHlim | 1530 | MPa
Tensiunea limită la oboseala încovoiere, | σFlim | 430 | MPa
Unghiul de înclinare a danturii | β | 14 | o (grade)

Calculul modulului frontal din solicitarea de contact

Valoarea modului exterior din solicitarea de contact se determină cu relaţia,

,

conform datelor următoare:

unde, T1 reprezintă momentul de torsiune al pinionului (Mt1), u - raportul de angrenare, β - unghiul de înclinare a danturii, z1 - numărul de dinţi ai pinionului cilindric, KA - factorul regimului de funcţionare, Kv - factorul dinamic, KHα - factorul repartizării neuniforme a sarcinii pe perechile de dinţi aflate în angrenare pentru solicitarea de contact, KHβ - factorul repartizării neuniforme a sarcinii pe lungimea dintelui pentru solicitarea de contact, ZE - factorul de elasticitate a materialelor roţilor, ZH - factorul zonei de contact, Zε - factorul gradului de acoperire pentru solicitarea de contact, ψd = b/d1 - factorul de lăţime, σHP - tensiunea admisibilă la solicitarea de contact.

Calculul modulului frontal exterior din solicitarea de încovoiere

Valoarea modului frontal din solicitarea de încovoiere se determină cu relaţia,

,

conform datelor următoare:

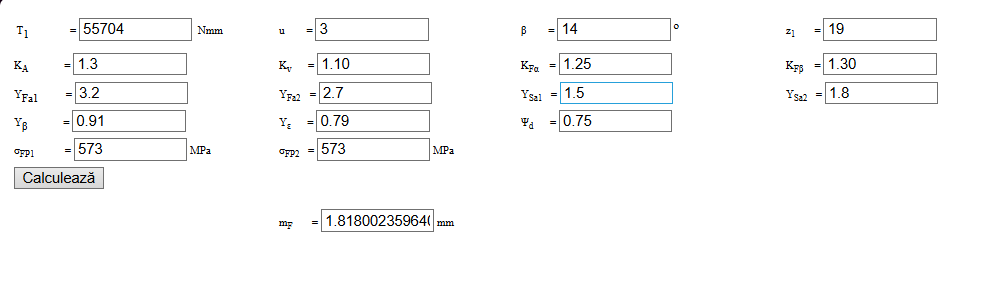
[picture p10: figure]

unde, T1 reprezintă momentul de torsiune al pinionului (Mt1), u - raportul de angrenare, β - unghiul de înclinare a danturii, z1 - numărul de dinţi al pinionului cilindric, KA - factorul regimului de funcţionare, Kv - factorul dinamic, KFα - factorul repartizării neuniforme a sarcinii pe perechile de dinţi aflate în angrenare pentru solicitarea de încovoiere, KFβ - factorul repartizării neuniforme a sarcinii pe lungimea dintelui pentru solicitarea de încovoiere, YFa1 - factorul de formă a dinţilor pinionului cilindric, YFa2 - factorul de formă a dinţilor roţii cilindrice, YSa1 - factorul de corecţie a tensiunii la baza dinţilor pinionului cilindric, YSa2 - factorul de corecţie a tensiunii la baza dinţilor roţii cilindrice, Yβ - factorul înclinării dinţilor, Yε - factorul gradului de acoperire pentru solicitarea de încovoiere, ψd = b/d1 - factorul de lăţime, σFP1 - tensiunea admisibilă la solicitarea de încovoiere pentru pinion, σFP2 - tensiunea admisibilă la solicitarea de încovoiere pentru roată.

Modulul frontal calculat

Ţinând cont de valorile modului frontal exterior obţinute din calculele la solicitările de contact şi de încovoiere rezultă,

mc = max (mH, mF) = max (1,89; 1,82) = 1,89 mm.

Astfel, se evidenţiază că solicitarea de contact este solicitarea principală.

Standardizarea modulului normal şi parametri geometrici principali

Ca urmare a standardizării modulului normal se pot determina parametri principali ai angrenajului cilindric.

Parametrul | Simbolul | Valoarea [mm] | Observaţii
Modulul frontal calculat | mc | 1,89
Modulul normal calculat | mnc = mc cos β | 1,833
Modulul normal (standardizat) | mn | 2
Modulul frontal | m = (m_n)/(cosβ) | 1,889
Diametrul de divizare al pinonului | d1 = m z1 | 35,9 | a = (d1 + d2)/2, 78,32 = (35,891+107,6730)/2 (se verifică)
Diametrul de divizare al roţii | d2 = m z2 | 107,673
Distanţa dintre axe de referinţă | a = (m_n (z_1 + z_2 ))/(2 cosβ) | 78,32
Lăţimea danturii roţii | b2 = b = ψd d1 | 27
Lăţimea danturii pinionului | b1 = b2 + 4…6 | 31

Modelarea profilelor dinţilor roţilor nedeplasate în angrenare (CATIA)

Personalizarea datelor de intrare

| Simbol teoretic | Semnificaţia
| αn | Unghiul de presiune (angrenare) normal [o]
| h_(an)^(*) | Coeficientul înălţimii capului dintelui
| c_(0n)^(*) | Coeficientul jocului la piciorul dintelui
| ρ_n^(*) | Coeficientul razei de racordare
| z1 | Numărul de dinţi ai pinionului
| z2 | Numărul de dinţi ai roţii
| mn | Modulul normal [mm]
| β | Unghiul de înclinare a danturii [o]
| aw | Distanţa dintre axe (reală) [mm]
| xn1 | Coeficientul deplasării de profil a danturii pinionului (zero, roţi nedeplasate)
| g | Grosimea coroanei [mm]

Verificarea modelului CATIA

| Simbol teoretic | Semnificaţia | Verificare
| u | Raportul de angrenare | u >1; 3> 1
| m | Modulul frontal [mm] | m > mn; 2.061 > 2
| a | Distanţa dintre axe de referinţă [mm] | a = aw ; 78.32 = 78.32
| α | Unghiul de presiune frontal [o] | α > αn; 20,562 > 20
| αw | Unghiul de angrenare frontal [o] | αw = α; 20,549 = 20,549
| aw | Distanţa dintre axe reală [mm] | aw (aw_rec) = a 78.32 = 78.32
| xns | Suma coeficeienţilor depasărilor | xns = 0
| xn2 | Coeficientul deplasării roţii | xn2 = 0
| rd1 | Raza cercului de divizare al pinionului [mm] | rd1+ rd2 = a 19,582+58,745=78,327
| rd2 | Raza cercului de divizare al roţii [mm]
| rw1 | Raza cercului de rostogolire al pinionului [mm] | rw1 = rd1; 19,582= 19,582
| rw2 | Raza cercului de rostogolire al roţii [mm] | rw2 = rd2; 58,745= 58,745
| rf1 | Raza cercului de picior al pinionului [mm] | rf1 < rd1; 17,082 < 19,582
| rf2 | Raza cercului de picior al roţii [mm] | rf2 < rd2 ; 56,238< 58,745
| ra1 | Raza cercului de divizare al pinionului [mm] | ra1 > rd1; 21,582 > 19,582
| ra2 | Raza cercului de divizare al roţii [mm] | ra2 > rd2; 60,738> 58,745

Modelul CATIA

Standardizarea distanţei dintre axe şi parametri geometrici principali

# Alegerea (standardizarea) distanţei dintre axe

Pentru distanţa dintre axe standard, aw = 80 mm, restricţiile impuse în vederea realizării angrenajului cu distanţa dintre axe impusă, - 0,5mn < aw – a ≤ mn devin:

-0,5 x 2 < 80 – 78,32 = 1,68 ≤ 2 (SE VERIFICA).

Determinarea parametrilor geometrici principali ai angrenajului deplasat

Denumirea parametrului | Relaţia de calcul | Valoarea | Unitatea de măsură | Observaţii
Unghiul de presiune frontal | | 20,5617 | [o] | αn = 20o
Unghiul de angrenare frontal | | 23,561 | [o]
Suma coeficienţi depasărilor de profil ale danturilor roţilor | | 0,899
Coeficientul deplasării de profil a danturii pinionului | | +0,4711 | | xn2 = +0,4278

Pentru asigurarea distanţei dintre axe impusă (aw = 80 mm) şi a unor rezistențe mărite la contact și încovoiere, în continuare, se vor considera următoarele valori:

Numărul de dinţi ai pinionului, z1 | Numărul de dinţi ai roţii, z2 | Coeficientul deplasării de profil a danturii pinionului, xn1 | Coeficientul deplasării de profil a danturii roţii, xn2 | Raportul de angrenare recalaculat, u_(rec2)
19 | 57 | +0,4711 | +0,4278 | 2,5

Modelarea şi verificarea angrenajului deplasat (CATIA)

Date de intrare

| αn | Unghiul de presiune (angrenare) normal [o]
| h_(an)^(*) | Coeficientul înălţimii capului dintelui
| c_(0n)^(*) | Coeficientul jocului la piciorul dintelui
| ρ_n^(*) | Coeficientul razei de racordare
| z1 | Numărul de dinţi ai pinionului (modificat)
| z2 | Numărul de dinţi ai roţii (modificat)
| mn | Modulul normal [mm]
| β | Unghiul de înclinare a danturii [o]
| aw | Distanţa dintre axe reală [mm]
| xn1 | Coeficientul deplasării de profil a danturii pinionului (calculat)
| g | Grosimea coroanei [mm]

Verificarea modelului

| Simbol teoretic | Semnificaţia | Verificare

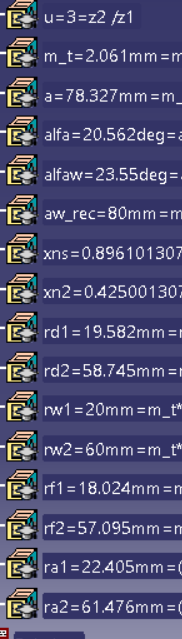
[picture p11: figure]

| u | Raportul de angrenare | u = u_(rec2) ;
| m | Modulul frontal [mm] | m > mn; 2,061 > 2
| a | Distanţa dintre axe de referinţă [mm] | a < aw ; 78,327 < 80
| α | Unghiul de presiune frontal [o] | α < αw, 20,562 < 23,55 (angr. PLUS)
| αw | Unghiul de angrenare fronatl [o]
| aw | Distanţa dintre axe reală [mm] (verificare) | aw > a; 80 > 78,327(angr. PLUS)
| xns | Suma coeficeienţilor depasărilor | xns > 0; 0,896 > 0 (angr. PLUS)
| xn2 | Coeficientul deplasării roţii
| rd1 | Raza cercului de divizare al pinionului [mm] | rw1,2 > rd1,2 (angr. PLUS) 20 > 19,582; 60>58,745 rd1+ rd2 = a; 19,582+58,745 =78,327 rw1+ rw2 = aw ; 20 + 60=80
| rd2 | Raza cercului de divizare al roţii [mm]
| rw1 | Raza cercului de rostogolire al pinionului [mm]
| rw2 | Raza cercului de rostogolire al roţii [mm]
| rf1 | Raza cercului de picior al pinionului [mm] | rf1 < rw1; 18,024 < 20
| rf2 | Raza cercului de picior al roţii [mm] | rf2 < rw2; 57,095 < 60
| ra1 | Raza cercului de divizare al pinionului [mm] | ra1 > rw1; 22,405 > 20
| ra2 | Raza cercului de divizare al roţii [mm] | ra2 > rw2; 61,476 > 60

Modelul CATIA

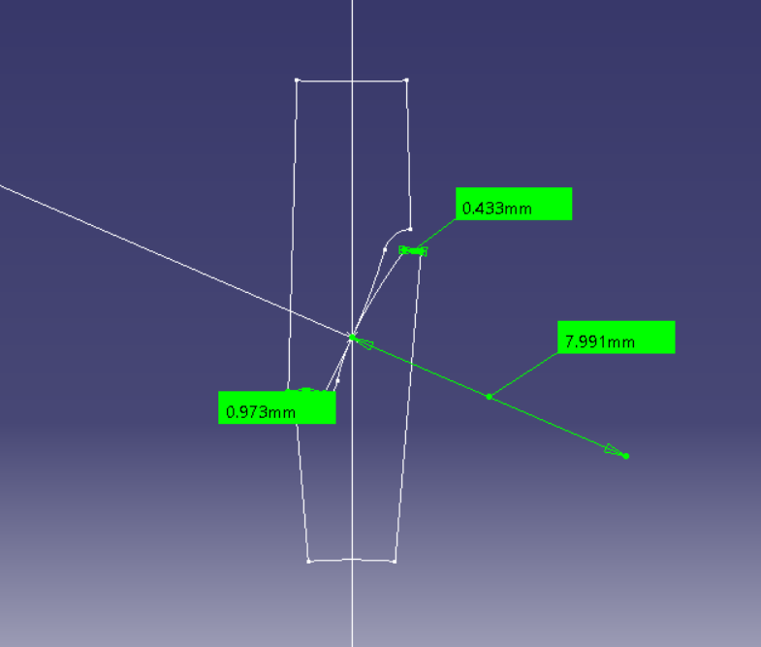
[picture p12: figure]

# Verificarea ascuţirii dinţilor roţilor

# În urma măsurării pe modelul CATIA, s1 = 0,433 mm şi s2 = 0,973 mm (v. figura de mai sus).

# Verificare: s1,2 > (0, 3…0,45) mn/2; 0,433 > 0,3 ...0,45 mm (se verifică).

Simularea şi verificarea continuității angrenării (CATIA)

Date de intrare

| Simbol teoretic | Semnificaţia
| αn | Unghiul de presiune (angrenare) normal [o]
| h_(an)^(*) | Coeficientul înălţimii capului dintelui
| c_(0n)^(*) | Coeficientul jocului la piciorul dintelui
| ρ_n^(*) | Coeficientul razei de racordare
| z1 | Numărul de dinţi ai pinionului
| z2 | Numărul de dinţi ai roţii
| mn | Modulul normal [mm]
| β | Unghiul de înclinare a danturii [o]
| aw | Distanţa dintre axe reală [mm]
| xn1 | Coeficientul deplasării de profil a danturii pinionului
| g | Grosimea coroanei [mm]
| Unghiul de rotire a dinţilor pinionului pentru simulare [o]

Modelul CATIA

Simularea angrenării şi verificarea continuităţii

Poziţii limită ale perechilor de dinţi în angrenare:

Intrarea în angrenare a perechii de dinţi n; T1A = 4,533 mm, pb = 6,032 mm | Ieşirea din angrenare a perechii de dinţi n+1; T1B = 12,879 mm

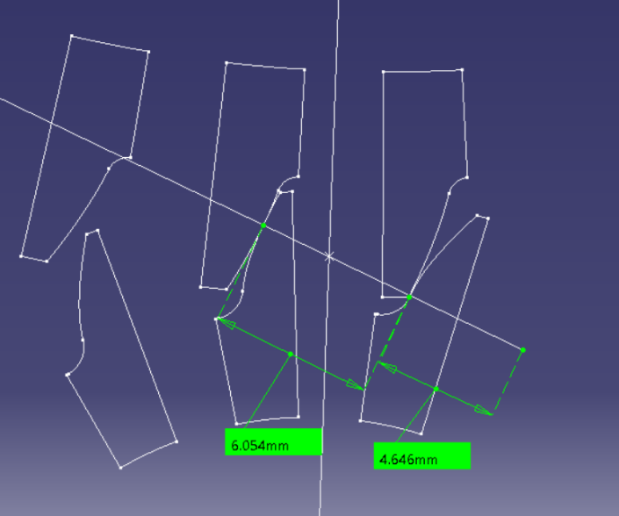
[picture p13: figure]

Intrarea în angrenare perechii de dinţi n-1; T1A = 4,646 mm, pb = 6,054 mm | Ieşirea din angrenare a perechii de dinţi n; T1B = 12.89mm

Determinarea valorii aproximative a gradului de acoperire frontal prin măsurare

ε_α^m = (AB)/(P_b) = (T_1 B-T_1 A)/(p_b) = = (12,884-4,589)/(6,043) = 1,372.

Valorile numerice sunt obţinute prin măsurare de cel puţin două ori, conform tebelului de mai sus; în această relaţia s-au considerat mediile aritmetice ale valorilor măsurate.

Determinarea valorii exacte a gradului de acoperire frontal

Din modelul CATIA rezultă,

Abaterea valorii gradului de acoperire obţinut prin măsurare, ε_α^m = 1,372, în raport cu gradul de acoperire calculat, εα = 1,381, Ab = -0,65%.

# 4. PREDIMENSIONAREA ARBORILOR ŞI ALEGEREA RULMENŢILOR

4.1 Structuri constructive ale subansamblelor arborilor

Subansamble arbori de intrare şi de ieşire

Semnificaţii notații

d_(A1)^(ST) – diametrul capului arborelui de intrare (standardizat), L_(A1)^(ST) – lungimea capului arborelui de intrare (standardizată), d_(A2)^(ST) – diametrul capului arborelui de ieşire (standardizat), L_(A2)^(ST) – lungimea capului arborelui de ieşire (standardizată), d_(R1) – diametrul interior al rulmenţilor arborelui de intrare, d_(R2) – diametrul interior al rulmenţilor arborelui de ieşire. ), d_(A2)^r – diametrul tronsonului arborelui de ieşire de sub roata cilindrică.

4.2 Predimensionarea arborilor

Alegerea materialelor arborilor şi tratamentelor termice

Caracteristici şi tratamente termice:

Oţelul | Limita la curgere/rupere [MPa] | Tensiunea admisibilă la încovoiere [MPa] | | | Tratamentul termic | Duritatea la suprafaţă | Duritatea în interior
| | Statică | Pulsatorie | Alternant simetrică
Marca | σc/σr | σaiI | σaiII | σaiIII | Îmbunătăţire/ Cementare | HB/HRC | HB

Arborele de intrare (corp comun cu pinionul cilindric)
20TiMnCr12 | 850/1100 | 330 | 150 | 90 | Cementare | 55…63 HRC | 300…350

Arborele de ieşire
C60 | 720/420 | 230 | 110 | 65 | Îmbunătăţire | 200…300 HB | 250…300

Calculul de predimensionare a arborilor

Diametrele capetelor arborilor de intrare și de ieșire se determină cu relaţia,

dAi = ³√((16 M_(ti))/(π τ_(ati))) ,

unde, considerând i = 1, 2, dA1 reprezintă diametrul arborelui de intrare, dA2 - diametrul arborelui de ieşire, Mt1 – momentul de torsiune al arborelui de intrare, Mt2 – momentul de torsiune al arborelui de ieşire, τat1 – tensiunea admisibilă la torsiune a materialului arborelui de intrare, τat2 – tensiunea admisibilă la torsiune a materialului arborelui de de ieşire.

Valorile parametrilor de calcul:

Parametrul | Arbore de intrare (A1) | Arbore de ieşire (A3)
Momentul de torsiune | Mt1 = 55704 Nmm | Mt2 = 158756 Nmm
Tensiunea admisibilă | τat1 = 25 MPa | τat2 = 35 MPa
Diametrul | dA1 = 22,47 mm | dA2 = 28,48 mm

Obs. Valorile diametrelor se vor rotunji.

Standardizarea capetelor arborilor de intrare/ieşire

Formă şi dimensiuni

Valorile parametrilor:

Denumire parametru | Arbore de intrare (A1) | Arbore de ieşire (A2)
Diametrul standard | d_(A1)^(ST) = 22 mm | d_(A2)^(ST) = 28 mm
Lungimea standard | L_(A1)^(ST) = 36 mm | L_(A2)^(ST) = 42 mm

Obs. S-au adoptat capete de arbori cu lungime scurtă.

4.3 Alegerea rulmenţilor şi montajelor

Alegerea rulmenţilor

Din considerente de încîrcare a rulmenților cu forte radiale medii și axiale mici se adoptă rulmenți radiali.

Date despre rulmenţi:

Arborele | Tipul rulmentului | Simbol | Dimensiuni [mm] | | | | | Capacitatea dinamică C [N]
| | | d | D | B | T | a
De intrare | Radial cu bile | 6205 | 35 | 72 | 17 | - | - | 25500
De ieşire | Radial cu bile | 6213 | 45 | 85 | 19 | - | - | 31000

Obs.

- diametrele tronsoanelor pe care se montează rulmenţii: dR1 = 35 mm, dR2 = 45 mm;
- pentru arborele de ieşire se adoptă diametrul tronsonului pe care se montează roata cilindrică,

d_(A2)^r = dR2 + 10 mm = 55 mm.

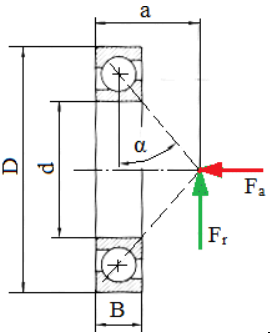
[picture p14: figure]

Alegerea montajelor rulmenţilor

Arbore de intrare

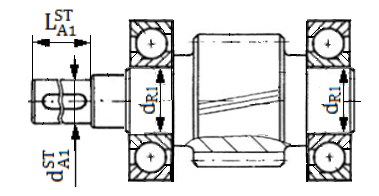
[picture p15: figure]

Arbore de ieşire

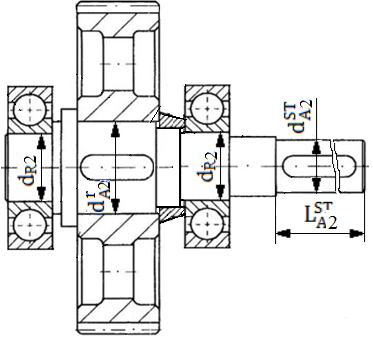
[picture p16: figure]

# 5. MODELAREA ŞI SIMULAREA CINEMATICĂ A MECANISMULUI

5.1 Generarea și simularea modelului cinematic (CATIA)

# 6. VERIFICAREA (DIMENSIONAREA) ANGRENAJULUI

6.1 Geometria angrenajului și roților cilindrice

Parametri geometrici

Valori ale parametrilor geometrici și tehnologici

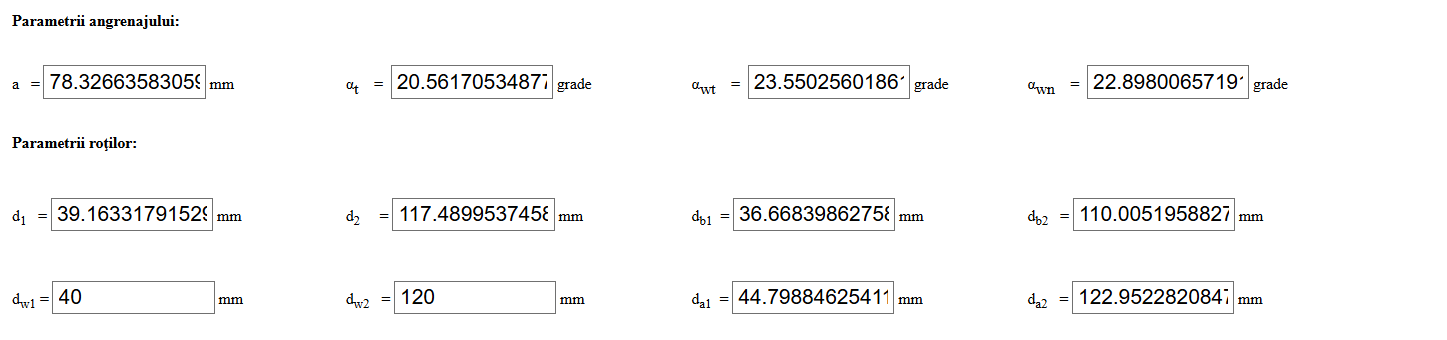
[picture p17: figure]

6.2 Adoptarea procedeelor de prelucrare şi de lubrifiere (ungere)

Schema de calcul a vitezei periferice

Valoarea vitezei periferice

Alegerea treptei de precizie şi procedeelor de prelucrare

Tipul danturii cilindrice | Treapta de precizie | Procedeul de prelucrare
Înclinată | 8 | Frezare îngrijită si mortezare

Alegerea rugozităţilor

Tipul danturii cilindrice | Rugozitatea flancului, Ra_f [μm] | Rugozitatea racordării, Ra_r [μm] | Procedeul de prelucrare final
Înclinată | 0,8 | 1,6 | Mortezare sau frezare, îngrijită

Alegerea tipului lubrifiantului (uleiului) şi vâscozităţii acestuia

Din considerente legate de cinematică și restricțiile de mediu se adoptă ulei de transmisii, TIN 300 EP.

6.5 Parametri de executie şi montaj ai angrenajului şi roţilor dinţate

Jocuri, abateri şi toleranţe ale angrenajului şi roţilor cilindrice

Jocului minim necesar, j_(min)^(nec) = (0,01…0,03)mn = (0,01…0,03) 2.5 = (0,025…0,0,75) mm; se adoptă 0,07 mm (70 μm).

Jocul minim normal, jnmin = 87 μm;

Tipul ajustajului, B.

Tipul toleranţei jocului dintre flancuri, b;

Toleranţele bătăii radiale: Fr = 45 μm, pentru pinion; = 63 μm, pentru roată.

Abatererile minime ale cotelor peste dinţi: Ews = 100 μm, pentru pinion; Ews = 140 μm, pentru roată.

Toleranţele cotelor peste dinţi: Tw = 60 μm, pentru pinion; Tw = 100 μm, pentru roată.

Abatererile minime ale grosimilor dinţilor pe coarde constante: Ecs = 100 μm, pentru pinion; Ecs = 140 μm, pentru roată.

Toleranţele grosimii dintelui pe coarda constantă: Tc = 100 μm, pentru pinion; Tc = 100 μm, pentru roată.

Abaterile limită ale distanţei dintre axe, fa = ±70 μm.

Personalizarea toleranțelor angrenajului şi roţilor ((W_(Nn) )_(-E_(Ws) -T_W)^(-E_(Ws)) ; (s_(cn) )_(-E_(cs) -T_c)^(-E_(cs)) ; aw ±fa):

- cota peste 3 dinţi, 19,85_(-0,16)^(-0,1) şi coarda constantă, 7,12_(-0,16)^(-0,1) , la înălţimea hcn = 4,4 mm, pentru pinion;
- cota peste 9 dinţi, 66,28_(-0,28)^(-0,18) şi coarda constantă, 6,35_(-0,16)^(-0,1) , la înălţimea hcn = 3,5 mm, pentru roată;
- distanţa dintre axe, 180 ±0,07 mm.

# 7. FORŢE ÎN ANGRENAJUL CILINDRIC

7.1 Schema forţelor din angrenajul cilindric RCil H

Direcţiile şi sensurile forţelor

Forţa tangenţială: direcţie tangentă la cercurile de rostogolire; sensul opus vitezei (forţă rezistentă), pentru roata conducătoare, şi acelaşi sens cu viteza (forţă motoare), pentru roata condusă.

Forţa radială: direcţie radială; sensul spre centrul roţii.

Forţa axială: direcţie axială; sensul determinat de direcţia de înclinare a dintelui şi de sensul de rotaţie al roţii.

Schema forţelor

Semnificaţiile notaţiilor:

Elemente structurale: angrenaj cilindric cu, 1 – pinion cilindric, 2 – roată cilindrică.

Forţe în angrenajul cilindric: F_t – forţa tangenţială; F_r – forţa radială; F_a – forţa axială.

7.3 Calculul forţelor din angrenajul cilindric

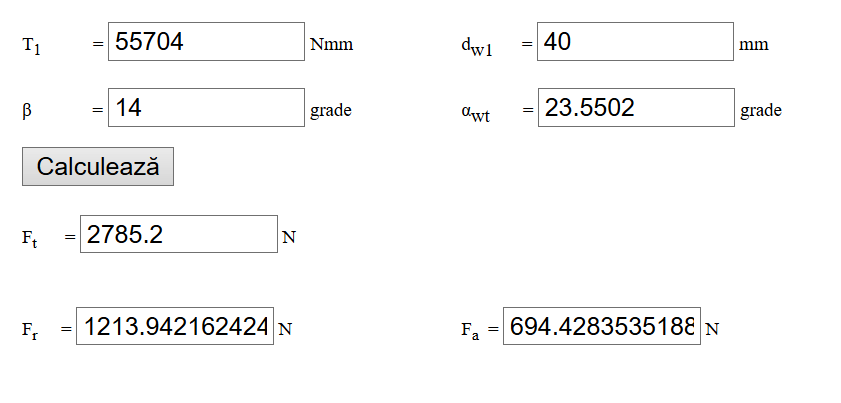
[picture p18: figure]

Angrenajul | Cilindric
Forţa | F_t | F_r | F_a
Valoarea forţei [N] | 2785,2 | 1213,9421 | 694,4283

# 8. ALEGEREA ŞI CALCULUL ASAMBLĂRILOR CU PENE PARALELE

8.1 Alegerea materialului, formelor şi dimensiunilor penelor paralele

Materialul penelor

Pentru toate penele se adoptă oțel pentru construcții mecanice E295 cu limita de curgere σ02 = 295 MPa, tensiunea admisibilă la strivire σas = 70…120 MPa, tensiunea admisibilă la forfecare τaf = 60…80 MPa.

Tipurile şi formelor penelor paralele

8.2 Calculul asamblărilor cu pene paralele

Parametri de calcul şi valori

Denumirea penei/ Parametrul | Pană paralelă I (tip A) | Pană paralelă II (tip A) | Pană paralelă III (tip C)
d [mm] | d_(A1)^(ST) = 22 | d_(A3)^r = 55 | d_(A3)^(ST) = 28
b[mm] | 6 | 16 | 8
h [mm] | 6 | 10 | 7
Mt [Nmm] | Mt1 = 55704 | Mt2 = 158756 | Mt2 = 158756
σas [MPa] | 80 | 100 | 100
lc [mm] | 21,1 | 11,5 | 32,4
l [mm] (STAS) | 28 | 45 | 50
t1 [mm] | 3,5 | 6 | 4
t2[mm] | 2,8 | 4,3 | 3,3

Pentru penele I şi III, deoarece lc < LA1,2, se adoptă o câte o pană, iar pentru pana II, deoarece lc < Lb, se adoptă, de asemenea, o singură pană.

# 9. PROIECTAREA FORMEI ŞI GENERAREA MODELELOR ÎN CATIA ALE PARTURILOR SUBANSAMBLELOR PRINCIPALE

Formele și dimensiunile parturilor se pot identifica în cadrul subansamblelor și/sau ansamblelor care se vor prezenta în continuare.

# 10. GENERARE SUBANSAMBLE RULMENŢI, ARBORI ŞI ANGRENAJ

10.1 Generare Subansamble rulmenţi

Rulment radial cu bile I | Rulment radial cu bile de II

10.2 Generare Subansamblu arbore de intrare

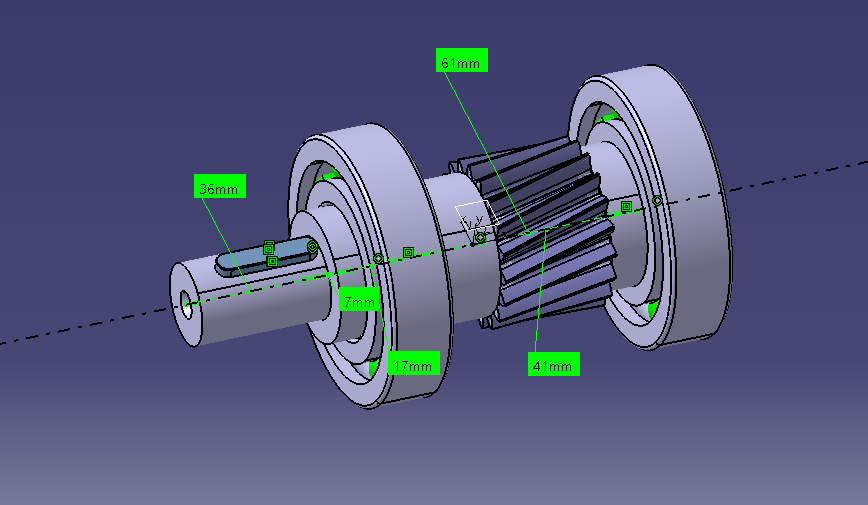
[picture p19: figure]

10.3 Generare Subansamblu arbore de ieşire

10.4 Generare Subansamblu angrenaj

(vedere izometrică)

(vedere în planul axelor)

# 11. GENERARE SUBANSAMBLE CARCASE

Carcasă superiară RCil H

Carcasă inferioară RCil H

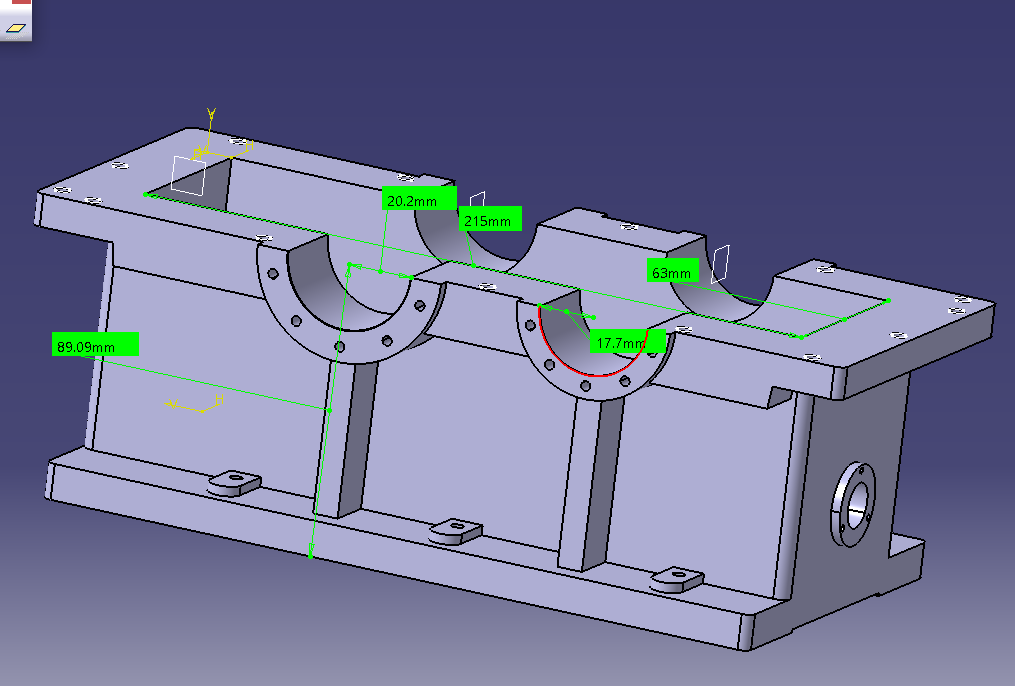
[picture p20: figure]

# 12. GENERARE MODEL 3D (ANSAMBU)

Ansamblu RCil H

# 13. VERIFICAREA ARBORILOR

13.1 Verificarea arborelui de intrare cu MDESIGN

Schema de încărcare RCil H

Date de intrare

Schema arborelui conform schiţei CATIA

Valori diametre şi lungimi

Diametrele și lungimile tronsoanelor: conform schiței CATIA (v. schema de mai sus).

Distanțe de poziţionare a reacţiunilor, B = 19 mm.

Grosimea coroanei dinţate, g = 1 mm.

Diametrul de rostogolire al pinionului, dw1 = 71,1628 mm.

Lungimile de calcul: L1 = 75 mm; L2 = 59,5 mm; L3 = 63 mm.

Valori forţe şi momente

Momentul de torsiune, Mt1 = 312071 Nmm.

Forţele de încărcare a pinionului cilindric: tangenţială, F_t = 8770,6 N; radială, F_r = 3582,8 N; axială, F_a^(II) = 2350 N.

Forţa de încărcare a capului arborelui, Fe = F_r = 3582,8 N.

Momentele de încovoiere, Mî1 = F_a dw1/2 = 2350*71,1628/2 = 83616,29 mm.

Turația arborelui

n = 625 rot/min, turaţia arborelui de intrare.

Date despre material

Tipul oţelului şi tratamentul termic: 18MoMnNi13, Cementare (carburare+călire+revenire înaltă).

Date despre concentratorii de tensiune

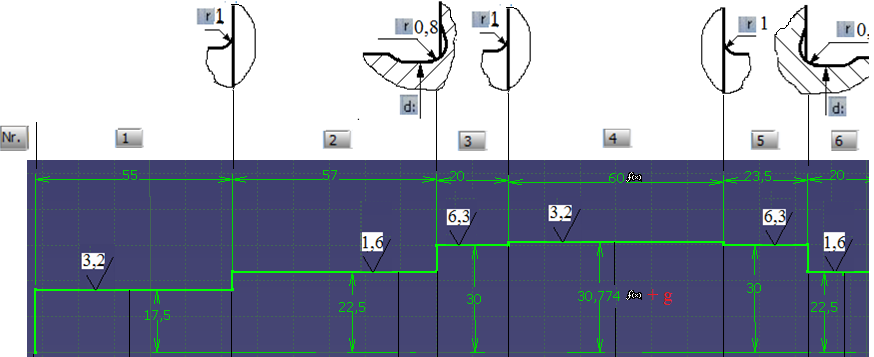
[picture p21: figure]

Modelul arborelui RCil H în MDESIGN

Obs. În continuare se vor prezenta rezultate pentru arborele RCil H. Pentru celelalte variante (RCil Vj și RCil Vs) se va parcurge aceleași etape introducând rezultatele corespunzătoare variantei respective.

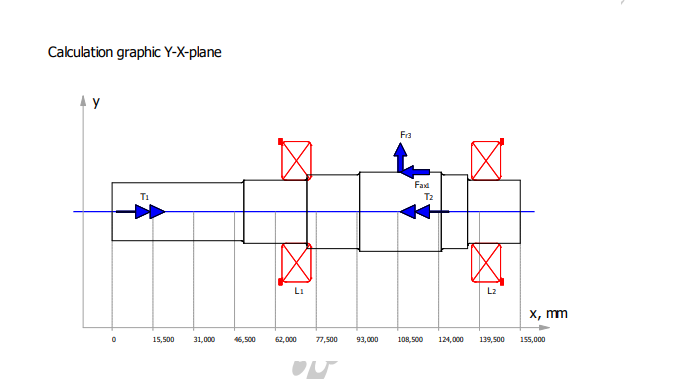
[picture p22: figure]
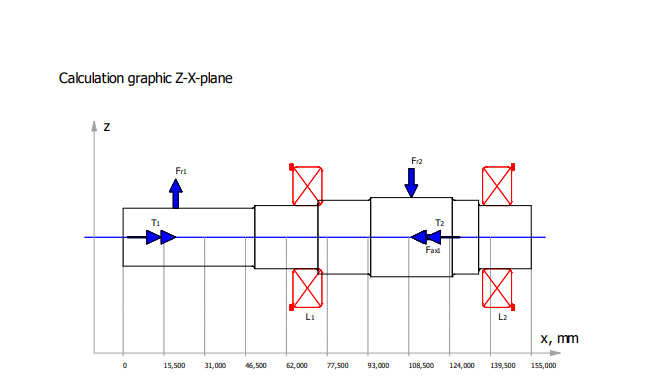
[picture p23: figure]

Valorile parametrilor geometrici ai tronsoanelor

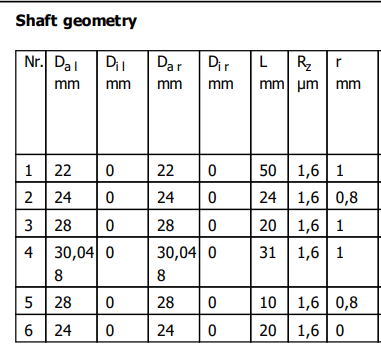
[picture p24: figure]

Date privind poziția punctului de calcul a săgeții la încovoiere; turația; considerarea greutății proprii, efectului giroscopic și rigidității rulmenților

3000

a

Date despre rulmenți

Date privind caracteristicile încărcărilor

Date despre încărcarea cu forțe axiale

Date despre încărcarea cu forțe radiale

Date despre încărcarea cu momente de torsiune

Date despre încărcări, calculul la oboseală și coeficienți de siguranță

Date despre material

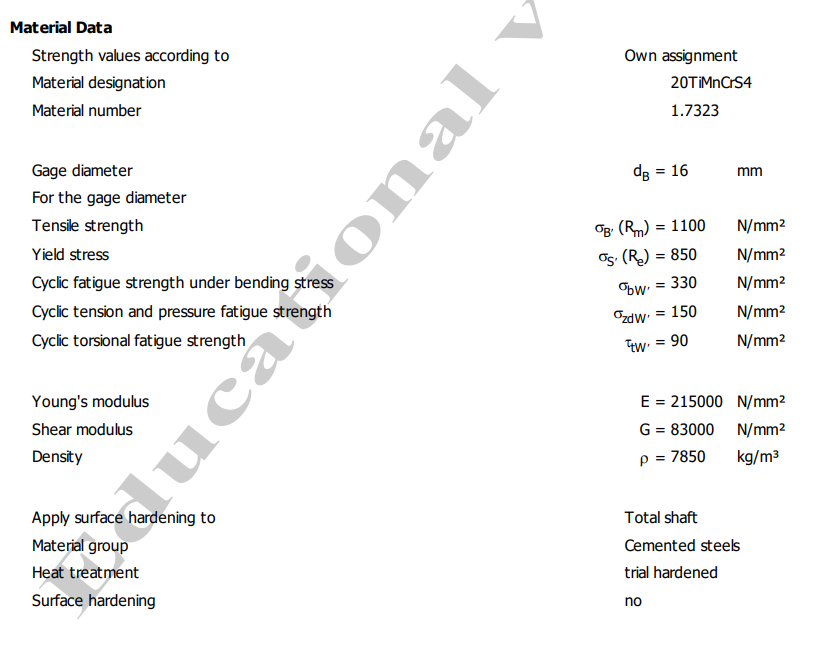
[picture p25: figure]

Valorile reacțiunilor în reazeme (lagăre cu rulmenți)

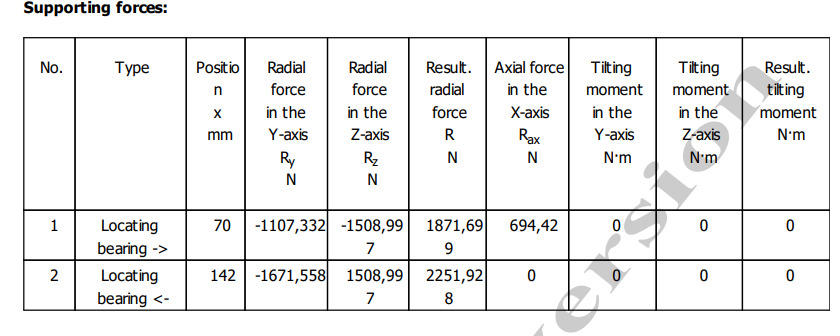
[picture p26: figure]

Obs. Valorile forțelor de reacțiune R (Result. radial force) se folosesc pentru calculul rulmenților.

Verificarea arborelui de intrare la solicitări compuse

Diagrama momentelor de încovoiere în planul YX

Diagrama momentelor de încovoiere în planul ZX

Diagrama momentelor de încovoiere rezultante

Diagrama momentelor de torsiune

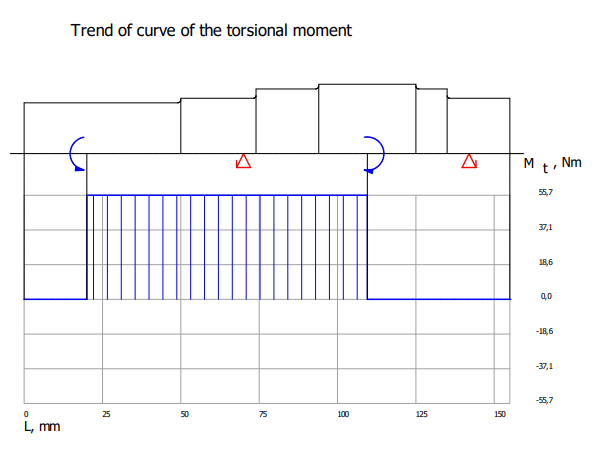
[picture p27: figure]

Diagrama tensiunilor de încovoiere rezultante

Diagrama tensiunilor echivalente

Diagrama coeficientului de siguranță

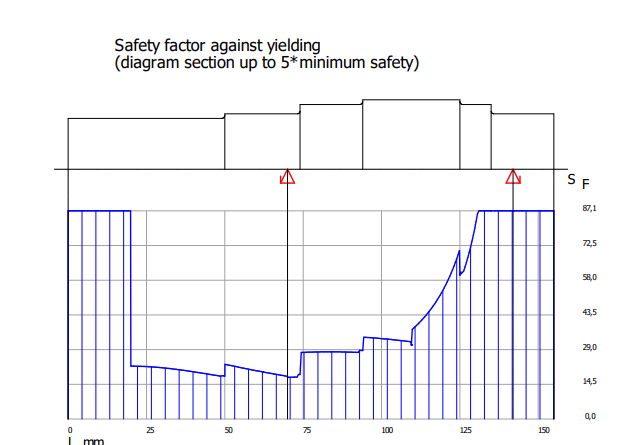
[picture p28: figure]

Verificarea arborelui de intrare la solicitări compuse

SFmin ≥ SF cu SFmin = 17,412; 17,412> 1,2 (se verifică)

Verificare la deformații de încovoiere (flexionale)

Diagramele săgeților și rotirilor

Valorile săgeților și rotirilor maxime și la jumătatea tronsonului cu dantura

Verificarea arborelui la deformații flexionale

- verificarea la deformații liniare (săgeți) în zona angrenajului, yx ≤ ya; ya = (0,01…0,03) * 4 = 0,04…0,12 mm;

0 < 0,04…0,12 mm (se verifică)

- verificarea la deformații liniare (săgeți) maxime: ymax ≤ ya; ya = 2,5 * 10⁻⁴ * 181 = 0,0452 mm;

0,035099 < 0,0452 mm (se verifică);

- verificare la deformații unghiulare (rotiri) maxime în lagăre: Θmax ≤ Θa; θa = 1,7.10⁻³ rad = 1,7.10⁻³ 180/π = 0,97o;

0,0024505 < 0,97 o (se verifică).

Verificarea arborelui la solicitări variabile (oboseală)

Diagrama coeficientului de siguranță la oboseală

Verificarea arborelui intermediar la solicitări variabile (oboseală)

SDmin ≥ SD: 1,98 > 1,2 (se verifică).

Verificarea la vibrații

Turațiile și vitezele critice la torsiune

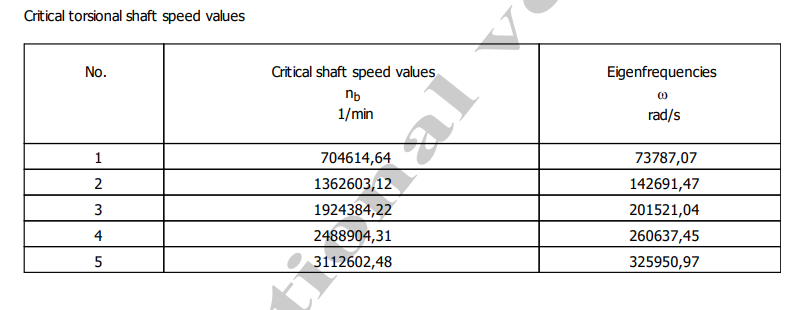
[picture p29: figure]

Turațiile și vitezele critice la încovoiere

Verificarea la vibrații (evitarea vibrațiilor critice)

- torsionale, (0…n) ≠ (0,8…1,2)f0:

(0…625) ≠ (0,8…1,2) 542914,75;

(0…625) ≠ (434331,8…651497,7) rot/min (se verifică).

- flexionale (de încovoiere), (0…n) ≠ (0,8…1,2)f0: (0…625) ≠ (0,8…1,2) 160374,53;

(0…625) ≠ (128299,62…192499,44) rot/min (se verifică).

# 14. VERIFICAREA RULMENŢILOR

Obs. În continuare se vor prezenta rezultate pentru verificarea rulmenților radiali cu bile. Pentru cazul rulmenților radial-axiali se vor prezenta etapele corespunzătoare celor din ghidul specific.

# 14.1 Verificarea rulmenţilor radiali pentru arborele de intrare

Schema de încărcare a rulmenţilor radiali

Date de intrare

Forţele exterioare

- radiale: FrA = 1871,699 N, FrB = 2251,928N.
- axiale: Fa1 = ±694,42; forţa Fa1 în funcţie de sensul de rotaţie poate avea semnul + (de la stânga la dreapta) sau – (de la dreapta la stânga) şi deci, în funcţie de acestea, se impune studiul pentru două cazuri (forța axială încarcă pe rând arborele în ambele sensuri).

Tipul rulmentului şi sarcina (capacitatea) dinamică de bază

Rulment radial cu bile (cod 6205) cu sarcina dinamică de bază C =25500 N, din catalogul pentru rulmenţi.

Factorii de influenţă pentru calcul

Factorul, f0 = 14,3; sarcina statică radială de bază, C0r = 36000 N; pentru (f_0 F_a)/(C_(0r)) = (14,3 * 694,42)/36000 = 0,276

şi joc radial normal (CN) rezultă factorii de influenţă: e = 0,28, X = 0,56, Y = 1,58.

Turaţia arborelui

Rulmenţii se rotesc cu turaţia arborelui de intrare, n = n1 =3000 rot/min.

Durata de funcţionare,

Durata de funcţionare a rulmenţilor este egală cu cea impusă RCil, Lh imp = 12000 ore

Sarcinile dinamice echivalente și rulmentul cel mai încărcat

Pentru rulmentul din lagărul L_A^(A_1)

(F_(a1))/(F_(rA)) = (694,42)/(1871,699) = 0,371> e = 0,28,

sarcina dinamică echivalentă,

PA = X FrA + Y Fa1 = 0,56⋅1871,699+1,58⋅694,42=1048,15+1097,18=2145,33 N

Pentru rulmentul din lagărul L_B^(A_1)

(F_(a1))/(F_(rB)) = 2350/(2251,928) = 0,308> e = 0,28,

sarcina dinamică echivalentă,

PB = X FrB + Y Fa1 = 0,56⋅2251,928+1,58⋅694,42=1261,08+1097,18=2358,26 N

Deoarece, PA < PB, rezultă că rulmentul din lagărul L_B^(A_1) este cel mai încărcat.

Verificarea rulmentului cel mai înărcat

Determinara durabilităţii rulmentului cel mai încărcat

LB = (C/(P_A))^p = (25500/(2358,26))^3 = 1265,8 milioane de rotaţii,

Determinara duratei de funcţionare a rulmentului cel mai încărcat

LhA = (L_A 10^6)/(n_1 60) = (1265,8 . 10^6)/(3000 . 60) = 7032,2 ore.

Verificarea rulmentului cel mai încărcat

LhA > Lh imp; 7032,2 > 11787,94 (se verifică).

# 15. MODELAREA ŞI GENERAREA DESENULUI DE ANSAMBLU

Obs. În continuare, se prezentă desenul RCil H. În cazul altei variante se va prezenta desenul corespunzător.

Desen de ansamblu RCil H

# 16. MODELAREA ŞI GENERAREA DESENELOR DE EXECUŢIE

Obs. În continuare, se prezentă desenele pentru arborele de intrare cu pinion cilindic, roata dințată cilindrică și arborele de ieșire din componența RCil H. În cazul unui proiect personalizat se vor prezenta desenele indicate în tema de proiectare.

Desen de execuţie Arbore de intrare cu pinion cilindric

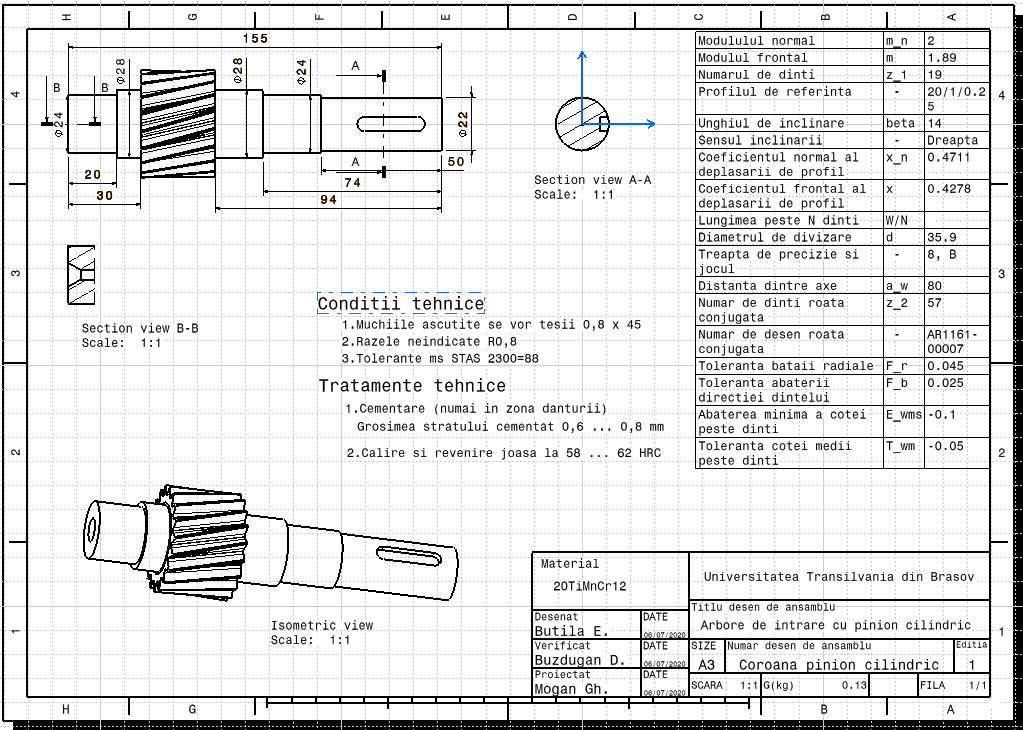
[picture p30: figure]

Desen de execuţie Roată dințată cilindrică

Desen de execuţie Arbore de ieşire

BIBLIOGRAFIE

1. Jula, A. ş.a. Organe de maşini, vol. I,II. Universitatea din Braşov, 1986, 1989.
2. Mogan, Gh. ş.a. Organe de maşini. Teorie-Proiectare-Aplicații, Ed Universității Transilvania din Braşov, 2012 (format electronic: www.mg.rrv.ro, user name: student; password: mogan).
3. Moldovean, Gh. ş.a. Angrenaje cilindrice şi conice. Calcul şi construcţie. Ed. LuxLibris, Braşov, 2001.
4. Moldovean, Gh. ş.a. Angrenaje cilindrice şi conice. Metodici de proiectare. Ed. LuxLibris, Braşov, 2002.
5. Rădulescu, C. Organe de maşini, vol. I, II, III. Universitatea Transilvania din Braşov, 1985.
6. *** Culegere de norme şi extrase din standarde pentru proiectarea elementelor componente ale maşinilor, vol. I. şi II. Universitatea din Braşov, 1984.

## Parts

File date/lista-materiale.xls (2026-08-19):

24 May 2026 12:43:10
Bill of Material: Product4
Quantity | Part Number | Type | Nomenclature | Revision
1 | Product2 | Assembly
1 | Subansamblue angrenaj | Assembly
1 | Product3 | Assembly
1 | Capac 1 | Part
1 | Capac 2 | Part
1 | Capac 3 | Part
1 | Capac 4 | Part
12 | ISO 4017 SCREW M3x10 STEEL GRADE A HEXAGON HEAD | Part
1 | Part1 | Part
12 | Saiba Grower Capace | Part
4 | ISO 4017 SCREW M5x30 STEEL GRADE A HEXAGON HEAD | Part
7 | ISO 4032 NUT M5 STEEL GRADE A HEXAGON | Part
3 | ISO 4018 SCREW M5x40 STEEL GRADE C HEXAGON HEAD | Part
Bill of Material: Product2
Quantity | Part Number | Type | Nomenclature | Revision
1 | Carcasa inferioara H | Part
1 | Buson de aerisire | Part
1 | Garnitura plata de etanşare | Part
1 | Vizor nivel de ulei | Part
1 | Garnitura plata vizor ulei | Part
2 | Stift Pozitionare | Part
Bill of Material: Subansamblue angrenaj
Quantity | Part Number | Type | Nomenclature | Revision
1 | Subansamblu arbore de intrare | Assembly
1 | Subansamblu arbore de iesire | Assembly
Bill of Material: Subansamblu arbore de intrare
Quantity | Part Number | Type | Nomenclature | Revision
2 | Rulment radial cu bile | Part
1 | Coroana pinion cilindric | Part
1 | Pana paralela I | Part
Bill of Material: Subansamblu arbore de iesire
Quantity | Part Number | Type | Nomenclature | Revision
1 | Arbore de iesire | Part
2 | Pana paralela 2 | Part
1 | Coroana roata cilindrica | Part
1 | Distantier | Part
2 | Rulment radial cu bile.1 | Part
Bill of Material: Product3
Quantity | Part Number | Type | Nomenclature | Revision
1 | Carcasa superioara H | Part
1 | Buşon de aerisire | Part
1 | Capac de vizitare | Part
1 | Garnitura capac vizitare | Part
8 | Şaibă Grower (varianta N) | Part
8 | ISO_4017_GRADES_A_B_HEXAGON_HEAD_SCREW | Part
Recapitulation of: Product4
Different parts: 30
Total parts: 81
Quantity | Part Number
1 | Carcasa inferioara H
1 | Buson de aerisire
1 | Garnitura plata de etanşare
1 | Vizor nivel de ulei
1 | Garnitura plata vizor ulei
2 | Stift Pozitionare
2 | Rulment radial cu bile
1 | Coroana pinion cilindric
1 | Pana paralela I
1 | Arbore de iesire
2 | Pana paralela 2
1 | Coroana roata cilindrica
1 | Distantier
2 | Rulment radial cu bile.1
1 | Carcasa superioara H
1 | Buşon de aerisire
1 | Capac de vizitare
1 | Garnitura capac vizitare
8 | Şaibă Grower (varianta N)
8 | ISO_4017_GRADES_A_B_HEXAGON_HEAD_SCREW
1 | Capac 1
1 | Capac 2
1 | Capac 3
1 | Capac 4
12 | ISO 4017 SCREW M3x10 STEEL GRADE A HEXAGON HEAD
1 | Part1
12 | Saiba Grower Capace
4 | ISO 4017 SCREW M5x30 STEEL GRADE A HEXAGON HEAD
7 | ISO 4032 NUT M5 STEEL GRADE A HEXAGON
3 | ISO 4018 SCREW M5x40 STEEL GRADE C HEXAGON HEAD

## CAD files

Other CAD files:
cad/Ansamblu H.CATProduct
cad/CATPart.10.1.1 Rulment radial cu bile de iesire.CATPart
cad/CATPart.10.1.1 Rulment radial cu bile intrare.CATPart
cad/CATPart.10.1.1 Rulment radial cu bile.CATPart
cad/CATPart.11.1.1.1 Generare Carcasa inferioara H.CATPart
cad/CATPart.11.1.2.1 Generare Carcasa superioara H.CATPart
cad/CATPart.11.2.1.1 Buson de aerisire.CATPart
cad/CATPart.11.2.1.2 Dop de golire.CATPart
cad/CATPart.11.2.1.3 Garnitura plata de etansare (1).CATPart
cad/CATPart.11.2.1.3 Garnitura plata de etansare.CATPart
cad/CATPart.11.2.2.1 Vizor nivel de ulei.CATPart
cad/CATPart.11.2.3.1 Capac de vizitare.CATPart
cad/CATPart.11.2.3.2 Garnitura capac de vizitare.CATPart
cad/CATPart.11.2.5.2 Saiba Grower.CATPart
cad/CATPart.12.2.1.1 Garnitura manseta de rotatie.CATPart
cad/CATPart.3.3.3.2.1 Model dinti in angrenare deplasat.CATPart
cad/CATPart.3.3.3.2.1 Model dinti in angrenare.CATPart
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

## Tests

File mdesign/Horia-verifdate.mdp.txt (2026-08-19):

<?xml version="1.0" encoding="UTF-16" standalone="yes"?>
<Document Signature="BSPMEDAT" Version="2.0" CreateBy="MDESIGN 2020 - Second Edition" CalcID="354" ID="354" CalcName="Shaft" ModuleVersion="18.0.13e">
	<Header Date="27.04.2026" User="" Customer="Student" Project="" VerifyBy="" XML_AUSEFILE="0">
		<AddDocuments/>
		<USERFIELDS>
			<USERFIELD ID="0"/>
			<USERFIELD ID="1"/>
			<USERFIELD ID="2"/>
			<USERFIELD ID="3"/>
			<USERFIELD ID="4"/>
		</USERFIELDS>
	</Header>
	<Data>
		<Parameter Name="COM_Geoschema" Type="combo" Visibility="1" Index="2" Value="General shaft geometry"/>
		<Parameter Name="COM_Lastkollektive" Type="combo" Visibility="0" Index="1" Value="no"/>
		<Parameter Name="COM_Berech" Type="combo" Visibility="1" Index="1" Value="Dynamic and static strength proof"/>
		<Parameter Name="in_SGruppe_Geometry" Type="void" Expanded="yes"/>
		<Parameter Name="GeoKerb" Type="combo" Visibility="0" Index="1" Value="Shaft fillet"/>
		<Parameter Name="D_D" Type="double" Visibility="0" Value="0" MeasureBase="mm" Measure="mm"/>
		<Parameter Name="D_1" Type="double" Visibility="0" Value="0" MeasureBase="mm" Measure="mm"/>
		<Parameter Name="diam" Type="double" Visibility="0" Value="0" MeasureBase="mm" Measure="mm"/>
		<Parameter Name="DiamN" Type="double" Visibility="0" Value="0" MeasureBase="mm" Measure="mm"/>
		<Parameter Name="tonne" Type="double" Visibility="0" Value="0" MeasureBase="mm" Measure="mm"/>
		<Parameter Name="L_k" Type="double" Visibility="0" Value="0" MeasureBase="mm" Measure="mm"/>
		<Parameter Name="r_r" Type="double" Visibility="0" Value="0" MeasureBase="mm" Measure="mm"/>
		<Parameter Name="m" Type="double" Visibility="0" Value="0" MeasureBase="mm" Measure="mm"/>
		<Parameter Name="dh" Type="double" Visibility="0" Value="0" MeasureBase="mm" Measure="mm"/>
		<Parameter Name="di" Type="double" Visibility="0" Value="0" MeasureBase="mm" Measure="mm"/>
		<Parameter Name="rz" Type="double" Visibility="0" Value="25" MeasureBase="µm" Measure="µm"/>
		<Parameter Name="Typ_berechbeta3" Type="combo" Visibility="0" Index="1" Value="no"/>
		<Parameter Name="Typ_berechbeta2" Type="combo" Visibility="0" Index="1" Value="no"/>
		<Parameter Name="ALFSIG_ZD" Type="double" Visibility="0" Value="0"/>
		<Parameter Name="ALFSIG_B" Type="double" Visibility="0" Value="0"/>
		<Parameter Name="ALFSIG_T" Type="double" Visibility="0" Value="0"/>
		<Parameter Name="NZD" Type="double" Visibility="0" Value="0"/>
		<Parameter Name="NB" Type="double" Visibility="0" Value="0"/>
		<Parameter Name="NT" Type="double" Visibility="0" Value="0"/>
		<Parameter Name="BSZDdBK" Type="double" Visibility="0" Value="0"/>
		<Parameter Name="BSBdBK" Type="double" Visibility="0" Value="0"/>
		<Parameter Name="BTdBK" Type="double" Visibility="0" Value="0"/>
		<Parameter Name="D_BK" Type="double" Visibility="0" Value="0" MeasureBase="mm" Measure="mm"/>
		<Parameter Name="GeoKerb2" Type="combo" Visibility="0" Index="1" Value="no"/>
		<Parameter Name="OverlappingNotches" Type="combo" Visibility="0" Index="1" Value="Wächter"/>
		<Parameter Name="D_D2" Type="double" Visibility="0" Value="0" MeasureBase="mm" Measure="mm"/>
		<Parameter Name="D_12" Type="double" Visibility="0" Value="0" MeasureBase="mm" Measure="mm"/>
		<Parameter Name="diam2" Type="double" Visibility="0" Value="0" MeasureBase="mm" Measure="mm"/>
		<Parameter Name="DiamN2" Type="double" Visibility="0" Value="0" MeasureBase="mm" Measure="mm"/>
		<Parameter Name="tonne2" Type="double" Visibility="0" Value="0" MeasureBase="mm" Measure="mm"/>
		<Parameter Name="L_k2" Type="double" Visibility="0" Value="0" MeasureBase="mm" Measure="mm"/>
		<Parameter Name="r_r2" Type="double" Visibility="0" Value="0" MeasureBase="mm" Measure="mm"/>
		<Parameter Name="m2" Type="double" Visibility="0" Value="0" MeasureBase="mm" Measure="mm"/>
		<Parameter Name="dh2" Type="double" Visibility="0" Value="0" MeasureBase="mm" Measure="mm"/>
		<Parameter Name="di2" Type="double" Visibility="0" Value="0" MeasureBase="mm" Measure="mm"/>
		<Parameter Name="rz2" Type="double" Visibility="0" Value="25" MeasureBase="µm" Measure="µm"/>
		<Parameter Name="Typ_berechbeta32" Type="combo" Visibility="0" Index="1" Value="no"/>
		<Parameter Name="Typ_berechbeta22" Type="combo" Visibility="0" Index="1" Value="no"/>
		<Parameter Name="ALFSIG_ZD2" Type="double" Visibility="0" Value="0"/>
		<Parameter Name="ALFSIG_B2" Type="double" Visibility="0" Value="0"/>
		<Parameter Name="ALFSIG_T2" Type="double" Visibility="0" Value="0"/>
		<Parameter Name="NZD2" Type="double" Visibility="0" Value="0"/>
		<Parameter Name="NB2" Type="double" Visibility="0" Value="0"/>
		<Parameter Name="NT2" Type="double" Visibility="0" Value="0"/>
		<Parameter Name="BSZDdBK2" Type="double" Visibility="0" Value="0"/>
		<Parameter Name="BSBdBK2" Type="double" Visibility="0" Value="0"/>
		<Parameter Name="BTdBK2" Type="double" Visibility="0" Value="0"/>
		<Parameter Name="D_BK2" Type="double" Visibility="0" Value="0" MeasureBase="mm" Measure="mm"/>
		<Parameter Name="LISTE_STUFE" Type="list" Visibility="1" Columns="24" Rows="6">
			<Column Name="DAL_STUFE" Type="double" MeasureBase="mm" Measure="mm" Visibility="1">
				<ColumnValue Value="22"/>
				<ColumnValue Value="24"/>
				<ColumnValue Value="28"/>
				<ColumnValue Value="30.048"/>
				<ColumnValue Value="28"/>
				<ColumnValue Value="24"/>
			</Column>
			<Column Name="DIL_STUFE" Type="double" MeasureBase="mm" Measure="mm" Visibility="1">
				<ColumnValue Value="0"/>
				<ColumnValue Value="0"/>
				<ColumnValue Value="0"/>
				<ColumnValue Value="0"/>
				<ColumnValue Value="0"/>
				<ColumnValue Value="0"/>
			</Column>
			<Column Name="DAR_STUFE" Type="double" MeasureBase="mm" Measure="mm" Visibility="1">
				<ColumnValue Value="22"/>
				<ColumnValue Value="24"/>
				<ColumnValue Value="28"/>
				<ColumnValue Value="30.048"/>
				<ColumnValue Value="28"/>
				<ColumnValue Value="24"/>
			</Column>
			<Column Name="DIR_STUFE" Type="double" MeasureBase="mm" Measure="mm" Visibility="1">
				<ColumnValue Value="0"/>
				<ColumnValue Value="0"/>
				<ColumnValue Value="0"/>
				<ColumnValue Value="0"/>
				<ColumnValue Value="0"/>
				<ColumnValue Value="0"/>
			</Column>
			<Column Name="L_STUFE" Type="double" MeasureBase="mm" Measure="mm" Visibility="1">
				<ColumnValue Value="50"/>
				<ColumnValue Value="24"/>
				<ColumnValue Value="20"/>
				<ColumnValue Value="31"/>
				<ColumnValue Value="10"/>
				<ColumnValue Value="20"/>
			</Column>
			<Column Name="R_RZ" Type="double" MeasureBase="µm" Measure="µm" Visibility="1">
				<ColumnValue Value="1.6"/>
				<ColumnValue Value="1.6"/>
				<ColumnValue Value="1.6"/>
				<ColumnValue Value="1.6"/>
				<ColumnValue Value="1.6"/>
				<ColumnValue Value="1.6"/>
			</Column>
			<Column Name="R" Type="double" MeasureBase="mm" Measure="mm" Visibility="1">
				<ColumnValue Value="1"/>
				<ColumnValue Value="0.8"/>
				<ColumnValue Value="1"/>
				<ColumnValue Value="1"/>
				<ColumnValue Value="0.8"/>
				<ColumnValue Value="0"/>
			</Column>
			<Column Name="D_KERB" Type="double" MeasureBase="mm" Measure="mm" Visibility="1">
				<ColumnValue Value="0"/>
				<ColumnValue Value="0"/>
				<ColumnValue Value="0"/>
				<ColumnValue Value="0"/>
				<ColumnValue Value="0"/>
				<ColumnValue Value="0"/>
			</Column>
			<Column Name="T_KERB" Type="double" MeasureBase="mm" Measure="mm" Visibility="1">
				<ColumnValue Value="0"/>
				<ColumnValue Value="0"/>
				<ColumnValue Value="0"/>
				<ColumnValue Value="0"/>
				<ColumnValue Value="0"/>
				<ColumnValue Value="0"/>
			</Column>
			<Column Name="ID_STUFE" Type="integer" Visibility="1">
				<ColumnValue Value="1"/>
				<ColumnValue Value="1"/>
				<ColumnValue Value="1"/>
				<ColumnValue Value="1"/>
				<ColumnValue Value="1"/>
				<ColumnValue Value="1"/>
			</Column>
			<Column Name="Ober_STUFE" Type="string" Visibility="0">
				<ColumnValue Value="no"/>
				<ColumnValue Value="no"/>
				<ColumnValue Value="no"/>
				<ColumnValue Value="no"/>
				<ColumnValue Value="no"/>
				<ColumnValue Value="no"/>
			</Column>
			<Column Name="Kv_STUFE" Type="double" Visibility="0">
				<ColumnValue Value="0"/>
				<ColumnValue Value="0"/>
				<ColumnValue Value="0"/>
				<ColumnValue Value="0"/>
				<ColumnValue Value="0"/>
				<ColumnValue Value="0"/>
			</Column>
			<Column Name="Kv2_STUFE" Type="double" Visibility="0">
				<ColumnValue Value="0"/>
				<ColumnValue Value="0"/>
				<ColumnValue Value="0"/>
				<ColumnValue Value="0"/>
				<ColumnValue Value="0"/>
				<ColumnValue Value="0"/>
			</Column>
			<Column Name="ALFA1_ST" Type="double" Visibility="0">
				<ColumnValue Value="0"/>
				<ColumnValue Value="0"/>
				<ColumnValue Value="0"/>
				<ColumnValue Value="0"/>
				<ColumnValue Value="0"/>
				<ColumnValue Value="0"/>
			</Column>
			<Column Name="ALFA2_ST" Type="double" Visibility="1">
				<ColumnValue Value="0"/>
				<ColumnValue Value="0"/>
				<ColumnValue Value="0"/>
				<ColumnValue Value="0"/>
				<ColumnValue Value="0"/>
				<ColumnValue Value="0"/>
			</Column>
			<Column Name="ALFA3_ST" Type="double" Visibility="1">
				<ColumnValue Value="0"/>
				<ColumnValue Value="0"/>
				<ColumnValue Value="0"/>
				<ColumnValue Value="0"/>
				<ColumnValue Value="0"/>
				<ColumnValue Value="0"/>
			</Column>
			<Column Name="N1_ST" Type="double" Visibility="1">
				<ColumnValue Value="0"/>
				<ColumnValue Value="0"/>
				<ColumnValue Value="0"/>
				<ColumnValue Value="0"/>
				<ColumnValue Value="0"/>
				<ColumnValue Value="0"/>
			</Column>
			<Column Name="N2_ST" Type="double" Visibility="1">
				<ColumnValue Value="0"/>
				<ColumnValue Value="0"/>
				<ColumnValue Value="0"/>
				<ColumnValue Value="0"/>
				<ColumnValue Value="0"/>
				<ColumnValue Value="0"/>
			</Column>
			<Column Name="N3_ST" Type="double" Visibility="1">
				<ColumnValue Value="0"/>
				<ColumnValue Value="0"/>
				<ColumnValue Value="0"/>
				<ColumnValue Value="0"/>
				<ColumnValue Value="0"/>
				<ColumnValue Value="0"/>
			</Column>
			<Column Name="beta1_st" Type="double" Visibility="1">
				<ColumnValue Value="0"/>
				<ColumnValue Value="0"/>
				<ColumnValue Value="0"/>
				<ColumnValue Value="0"/>
				<ColumnValue Value="0"/>
				<ColumnValue Value="0"/>
			</Column>
			<Column Name="beta2_st" Type="double" Visibility="1">
				<ColumnValue Value="0"/>
				<ColumnValue Value="0"/>
				<ColumnValue Value="0"/>
				<ColumnValue Value="0"/>
				<ColumnValue Value="0"/>
				<ColumnValue Value="0"/>
			</Column>
			<Column Name="beta3_st" Type="double" Visibility="1">
				<ColumnValue Value="0"/>
				<ColumnValue Value="0"/>
				<ColumnValue Value="0"/>
				<ColumnValue Value="0"/>
				<ColumnValue Value="0"/>
				<ColumnValue Value="0"/>
			</Column>
			<Column Name="dBK_st" Type="double" MeasureBase="mm" Measure="mm" Visibility="1">
				<ColumnValue Value="0"/>
				<ColumnValue Value="0"/>
				<ColumnValue Value="0"/>
				<ColumnValue Value="0"/>
				<ColumnValue Value="0"/>
				<ColumnValue Value="0"/>
			</Column>
			<Column Name="D_STUFE" Type="double" MeasureBase="mm" Measure="mm" Visibility="1">
				<ColumnValue Value="0"/>
				<ColumnValue Value="0"/>
				<ColumnValue Value="0"/>
				<ColumnValue Value="0"/>
				<ColumnValue Value="0"/>
				<ColumnValue Value="0"/>
			</Column>
		</Parameter>
		<Parameter Name="D_I" Type="double" Visibility="0" Value="0" MeasureBase="mm" Measure="mm"/>
		<Parameter Name="K_FORM" Type="list" Visibility="1" Columns="19" Rows="0">
			<Column Name="ID_KFORM" Type="integer" Visibility="1"/>
			<Column Name="TYPE_K_FORM" Type="string" Visibility="0"/>
			<Column Name="X_KF" Type="double" MeasureBase="mm" Measure="mm" Visibility="1"/>
			<Column Name="DD_KF" Type="double" MeasureBase="mm" Measure="mm" Visibility="1"/>
			<Column Name="T_KF" Type="double" MeasureBase="mm" Measure="mm" Visibility="1"/>
			<Column Name="R_KF" Type="double" MeasureBase="mm" Measure="mm" Visibility="1"/>
			<Column Name="DH_kf" Type="double" MeasureBase="mm" Measure="mm" Visibility="1"/>
			<Column Name="M_BREITE" Type="double" MeasureBase="mm" Measure="mm" Visibility="1"/>
			<Column Name="L_KF" Type="double" MeasureBase="mm" Measure="mm" Visibility="1"/>
			<Column Name="ALFA1_kf" Type="double" Visibility="1"/>
			<Column Name="ALFA2_kf" Type="double" Visibility="1"/>
			<Column Name="ALFA3_kf" Type="double" Visibility="1"/>
			<Column Name="N1_kf" Type="double" Visibility="1"/>
			<Column Name="N2_kf" Type="double" Visibility="1"/>
			<Column Name="N3_kf" Type="double" Visibility="1"/>
			<Column Name="bszdDBK_kf" Type="double" Visibility="1"/>
			<Column Name="bsbDBK_kf" Type="double" Visibility="1"/>
			<Column Name="bttDBK_kf" Type="double" Visibility="1"/>
			<Column Name="dBK_kf" Type="double" MeasureBase="mm" Measure="mm" Visibility="1"/>
		</Parameter>
		<Parameter Name="COM_VERGdeff" Type="combo" Visibility="0" Index="1" Value="no"/>
		<Parameter Name="deff" Type="double" Visibility="0" Value="0" MeasureBase="mm" Measure="mm"/>
		<Parameter Name="DistanceToCrossSec" Type="double" Visibility="1" Value="142" MeasureBase="mm" Measure="mm"/>
		<Parameter Name="Drehzahl" Type="double" Visibility="1" Value="625" MeasureBase="1/min" Measure="1/min"/>
		<Parameter Name="B_BE" Type="combo" Visibility="1" Index="2" Value="horizontal shaft"/>
		<Parameter Name="B_KB" Type="boolean" Visibility="1" Value="0"/>
		<Parameter Name="B_DC" Type="boolean" Visibility="0" Value="0"/>
		<Parameter Name="B_LB" Type="boolean" Visibility="1" Value="0"/>
		<Parameter Name="B_BREITE_LAGER" Type="boolean" Visibility="0" Value="0"/>
		<Parameter Name="LISTE_LAGER" Type="list" Visibility="1" Columns="10" Rows="2">
			<Column Name="ID_LAGER" Type="integer" Visibility="1">
				<ColumnValue Value="2"/>
				<ColumnValue Value="3"/>
			</Column>
			<Column Name="T0LAGER" Type="string" Visibility="0">
				<ColumnValue Value="Locating bearing -&gt;"/>
				<ColumnValue Value="Locating bearing &lt;-"/>
			</Column>
			<Column Name="L0LAGER" Type="double" MeasureBase="mm" Measure="mm" Visibility="1">
				<ColumnValue Value="70"/>
				<ColumnValue Value="142"/>
			</Column>
			<Column Name="CR_LAGER" Type="double" MeasureBase="N/m" Measure="N/m" Visibility="1">
				<ColumnValue Value="1e+015"/>
				<ColumnValue Value="1e+015"/>
			</Column>
			<Column Name="CALPHA_LAGER" Type="double" MeasureBase="N·m" Measure="N·m" Visibility="0">
				<ColumnValue Value="0"/>
				<ColumnValue Value="0"/>
			</Column>
			<Column Name="CBETTA_LAGER" Type="double" MeasureBase="N·m" Measure="N·m" Visibility="0">
				<ColumnValue Value="0"/>
				<ColumnValue Value="0"/>
			</Column>
			<Column Name="CR_LAGER1" Type="double" MeasureBase="N/m" Measure="N/m" Visibility="0">
				<ColumnValue Value="1e+015"/>
				<ColumnValue Value="1e+015"/>
			</Column>
			<Column Name="CALPHA_LAGER1" Type="double" MeasureBase="N·m" Measure="N·m" Visibility="1">
				<ColumnValue Value="0"/>
				<ColumnValue Value="0"/>
			</Column>
			<Column Name="CBETTA_LAGER1" Type="double" MeasureBase="N·m" Measure="N·m" Visibility="1">
				<ColumnValue Value="0"/>
				<ColumnValue Value="0"/>
			</Column>
			<Column Name="BREITE_LAGER" Type="double" MeasureBase="mm" Measure="mm" Visibility="1">
				<ColumnValue Value="0"/>
				<ColumnValue Value="0"/>
			</Column>
		</Parameter>
		<Parameter Name="LISTE_MASS" Type="list" Visibility="1" Columns="4" Rows="0">
			<Column Name="X_MASS" Type="double" MeasureBase="mm" Measure="mm" Visibility="1"/>
			<Column Name="J_MASS" Type="double" MeasureBase="kg·m²" Measure="kg·m²" Visibility="1"/>
			<Column Name="JYY_MASS" Type="double" MeasureBase="kg·m²" Measure="kg·m²" Visibility="1"/>
			<Column Name="M_MASS" Type="double" MeasureBase="kg" Measure="kg" Visibility="1"/>
		</Parameter>
		<Parameter Name="in_SGruppe_Lastdaten" Type="void" Expanded="yes"/>
		<Parameter Name="COM_BeansprZD" Type="combo" Visibility="1" Index="1" Value="Dynamically pure cyclic"/>
		<Parameter Name="KF_ZD" Type="double" Visibility="0" Value="0"/>
		<Parameter Name="COM_BeansprB" Type="combo" Visibility="1" Index="1" Value="Dynamically pure cyclic"/>
		<Parameter Name="KF_B" Type="double" Visibility="0" Value="0"/>
		<Parameter Name="COM_BeansprT" Type="combo" Visibility="1" Index="1" Value="Dynamically pure cyclic"/>
		<Parameter Name="KF_T" Type="double" Visibility="0" Value="0"/>
		<Parameter Name="Faktor_ZD" Type="double" Visibility="1" Value="1"/>
		<Parameter Name="Faktor_B" Type="double" Visibility="1" Value="1"/>
		<Parameter Name="Faktor_T" Type="double" Visibility="1" Value="1"/>
		<Parameter Name="Typ_Beanspruch" Type="combo" Visibility="0" Index="1" Value="Loads"/>
		<Parameter Name="LISTE_LastkollekBelastungen" Type="list" Visibility="0" Columns="4" Rows="0">
			<Column Name="LastKol_Fzd" Type="double" MeasureBase="N" Measure="N" Visibility="1"/>
			<Column Name="LastKol_Mb" Type="double" MeasureBase="N·m" Measure="N·m" Visibility="1"/>
			<Column Name="LastKol_Mt" Type="double" MeasureBase="N·m" Measure="N·m" Visibility="1"/>
			<Column Name="LastKol_q" Type="double" MeasureBase="%" Measure="%" Visibility="1"/>
		</Parameter>
		<Parameter Name="LISTE_LastkollekSpannungen" Type="list" Visibility="0" Columns="4" Rows="0">
			<Column Name="LastKol_Sigmazd" Type="double" MeasureBase="N/mm²" Measure="N/mm²" Visibility="1"/>
			<Column Name="LastKol_Sigmab" Type="double" MeasureBase="N/mm²" Measure="N/mm²" Visibility="1"/>
			<Column Name="LastKol_Tauta" Type="double" MeasureBase="N/mm²" Measure="N/mm²" Visibility="1"/>
			<Column Name="LastKol_Sigmaq" Type="double" MeasureBase="%" Measure="%" Visibility="1"/>
		</Parameter>
		<Parameter Name="F_ZDA" Type="double" Visibility="0" Value="0" MeasureBase="N" Measure="N"/>
		<Parameter Name="F_ZDM" Type="double" Visibility="0" Value="0" MeasureBase="N" Measure="N"/>
		<Parameter Name="F_ZDMAX" Type="double" Visibility="0" Value="0" MeasureBase="N" Measure="N"/>
		<Parameter Name="SIGMA_ZDA" Type="double" Visibility="0" Value="0" MeasureBase="N/mm²" Measure="N/mm²"/>
		<Parameter Name="SIGMA_ZDM" Type="double" Visibility="0" Value="0" MeasureBase="N/mm²" Measure="N/mm²"/>
		<Parameter Name="SIGMA_ZDMAX" Type="double" Visibility="0" Value="0" MeasureBase="N/mm²" Measure="N/mm²"/>
		<Parameter Name="M_BA" Type="double" Visibility="0" Value="0" MeasureBase="N·m" Measure="N·m"/>
		<Parameter Name="M_BM" Type="double" Visibility="0" Value="0" MeasureBase="N·m" Measure="N·m"/>
		<Parameter Name="M_BMAX" Type="double" Visibility="0" Value="0" MeasureBase="N·m" Measure="N·m"/>
		<Parameter Name="SIGMA_BA" Type="double" Visibility="0" Value="0" MeasureBase="N/mm²" Measure="N/mm²"/>
		<Parameter Name="SIGMA_BM" Type="double" Visibility="0" Value="0" MeasureBase="N/mm²" Measure="N/mm²"/>
		<Parameter Name="SIGMA_BMAX" Type="double" Visibility="0" Value="0" MeasureBase="N/mm²" Measure="N/mm²"/>
		<Parameter Name="M_TA" Type="double" Visibility="0" Value="0" MeasureBase="N·m" Measure="N·m"/>
		<Parameter Name="M_TM" Type="double" Visibility="0" Value="0" MeasureBase="N·m" Measure="N·m"/>
		<Parameter Name="M_TMAX" Type="double" Visibility="0" Value="0" MeasureBase="N·m" Measure="N·m"/>
		<Parameter Name="TAUSH_TA" Type="double" Visibility="0" Value="0" MeasureBase="N/mm²" Measure="N/mm²"/>
		<Parameter Name="TAUSH_TM" Type="double" Visibility="0" Value="0" MeasureBase="N/mm²" Measure="N/mm²"/>
		<Parameter Name="TAUSH_TMAX" Type="double" Visibility="0" Value="0" MeasureBase="N/mm²" Measure="N/mm²"/>
		<Parameter Name="LISTE_AXIAL" Type="list" Visibility="1" Columns="4" Rows="1">
			<Column Name="X_AXIAL" Type="double" MeasureBase="mm" Measure="mm" Visibility="1">
				<ColumnValue Value="109.5"/>
			</Column>
			<Column Name="F_AXIAL" Type="double" MeasureBase="N" Measure="N" Visibility="1">
				<ColumnValue Value="-694.42"/>
			</Column>
			<Column Name="R_AXIAL" Type="double" MeasureBase="mm" Measure="mm" Visibility="1">
				<ColumnValue Value="15.024"/>
			</Column>
			<Column Name="ALFA_A" Type="double" MeasureBase="°" Measure="°" Visibility="1">
				<ColumnValue Value="0"/>
			</Column>
		</Parameter>
		<Parameter Name="LISTE_RADIAL" Type="list" Visibility="1" Columns="3" Rows="3">
			<Column Name="X_RADIAL" Type="double" MeasureBase="mm" Measure="mm" Visibility="1">
				<ColumnValue Value="20"/>
				<ColumnValue Value="109.5"/>
				<ColumnValue Value="109.5"/>
			</Column>
			<Column Name="F_RADIAL" Type="double" MeasureBase="N" Measure="N" Visibility="1">
				<ColumnValue Value="-1213.9421"/>
				<ColumnValue Value="-1213.9421"/>
				<ColumnValue Value="-2785"/>
			</Column>
			<Column Name="ALFA_R" Type="double" MeasureBase="°" Measure="°" Visibility="1">
				<ColumnValue Value="270"/>
				<ColumnValue Value="90"/>
				<ColumnValue Value="180"/>
			</Column>
		</Parameter>
		<Parameter Name="LISTE_Q" Type="list" Visibility="1" Columns="5" Rows="0">
			<Column Name="X_STREC" Type="double" MeasureBase="mm" Measure="mm" Visibility="1"/>
			<Column Name="Q1_STREC" Type="double" MeasureBase="N/mm" Measure="N/mm" Visibility="1"/>
			<Column Name="Q2_STREC" Type="double" MeasureBase="N/mm" Measure="N/mm" Visibility="1"/>
			<Column Name="L_STREC" Type="double" MeasureBase="mm" Measure="mm" Visibility="1"/>
			<Column Name="ALFA_Q" Type="double" MeasureBase="°" Measure="°" Visibility="1"/>
		</Parameter>
		<Parameter Name="LISTE_BM" Type="list" Visibility="1" Columns="3" Rows="0">
			<Column Name="X_BM" Type="double" MeasureBase="mm" Measure="mm" Visibility="1"/>
			<Column Name="MBIEGE_NM" Type="double" MeasureBase="N·m" Measure="N·m" Visibility="1"/>
			<Column Name="ALFA_MB" Type="double" MeasureBase="°" Measure="°" Visibility="1"/>
		</Parameter>
		<Parameter Name="LISTE_TM" Type="list" Visibility="1" Columns="5" Rows="2">
			<Column Name="X_TM" Type="double" MeasureBase="mm" Measure="mm" Visibility="1">
				<ColumnValue Value="20"/>
				<ColumnValue Value="109.5"/>
			</Column>
			<Column Name="MTORSION_NM" Type="double" MeasureBase="N·m" Measure="N·mm" Visibility="1">
				<ColumnValue Value="55.704"/>
				<ColumnValue Value="55.704"/>
			</Column>
			<Column Name="Leist" Type="double" MeasureBase="kW" Measure="kW" Visibility="1">
				<ColumnValue Value="0"/>
				<ColumnValue Value="0"/>
			</Column>
			<Column Name="ID_RIEB" Type="integer" Visibility="1">
				<ColumnValue Value="1"/>
				<ColumnValue Value="2"/>
			</Column>
			<Column Name="Rieb" Type="string" Visibility="0">
				<ColumnValue Value="drive"/>
				<ColumnValue Value="takeoff"/>
			</Column>
		</Parameter>
		<Parameter Name="LF" Type="combo" Visibility="1" Index="1" Value="Constant mean stress (loading case 1)"/>
		<Parameter Name="Chek_NdNl" Type="combo" Visibility="1" Index="2" Value="yes"/>
		<Parameter Name="N_D" Type="integer" Visibility="0" Value="0"/>
		<Parameter Name="N_L" Type="integer" Visibility="0" Value="0"/>
		<Parameter Name="dN_D" Type="double" Visibility="1" Value="1000000"/>
		<Parameter Name="dN_L" Type="double" Visibility="1" Value="1e+007"/>
		<Parameter Name="dQsig" Type="double" Visibility="1" Value="5"/>
		<Parameter Name="dQtau" Type="double" Visibility="1" Value="8"/>
		<Parameter Name="S_DMIN" Type="double" Visibility="1" Value="1.2"/>
		<Parameter Name="S_FMIN" Type="double" Visibility="1" Value="1.2"/>
		<Parameter Name="S_GMIN" Type="double" Visibility="1" Value="1.2"/>
		<Parameter Name="in_SGruppe_Werkstoffdaten" Type="void" Expanded="yes"/>
		<Parameter Name="TYPE_CALC" Type="combo" Visibility="1" Index="2" Value="Own assignment"/>
		<Parameter Name="W_STOFF" Type="string" Visibility="0" Value="18MoCrS4"/>
		<Parameter Name="WERKST_ANDERE" Type="string" Visibility="1" Value="20TiMnCrS4"/>
		<Parameter Name="prq_Werkst" Type="string" Visibility="0" Value=""/>
		<Parameter Name="pr_Werkst" Type="string" Visibility="0" Value="18MoCrS4"/>
		<Parameter Name="Werkstoffnummer" Type="string" Visibility="1" Value="1.7323"/>
		<Parameter Name="prq_Num" Type="string" Visibility="0" Value=""/>
		<Parameter Name="pr_Num" Type="string" Visibility="0" Value="1.7323"/>
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

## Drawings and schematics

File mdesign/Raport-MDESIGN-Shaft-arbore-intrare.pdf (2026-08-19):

## Shaft

MDESIGN 2020 - Second Edition

Producer: | Project:
Verified by: | Date: 27.04.2026

Customer: Student

Last updated: 13.05.2026 | Module version: 18.0.13e | Page: 1 / 31

This program allows to prove the bearing ability for shafts and axles. The calculation base is provided by DIN 743, edition of December 2012.

The proof of the bearing ability for shafts an axles is produced by defining a calculated safety. This safety is divided in the safety against fatigue fracture and the residual deformation (and flaw or forced break).

When calculating the avoidance of fatigue fracture, constant stress amplitudes being equivalent to damaging loads are taken as a basis. These ones are resulting from the predetermined loads. When proving against the residual deformation or forced break, designated as a safety against yielding, only the maximum occurring load is determinant. This one is resulting from the predetermined loads, too.

The calculation of factors of safety is related only to the point of a clear notch effect. For it, 9 calculable notches are at your disposal due to the graphical selection, principally.

The scope is limited to steels. Welded members should be calculated separately. But the utilized standard or the present program is ineffective for this purpose!

The calculation base for the module Shaft Calculation is provided by DIN 743, edition of December 2012, part 1-4 “ Tragfähigkeitsberechnung von Wellen and Achsen” (“Calculation of bearing capacity of shafts and axles”).

Input data:

Shaft calculation in accordance with DIN 743 - extended version

Geometry scheme | General shaft geometry
Calculation process | Dynamic and static strength proof

Geometry
Shaft geometry

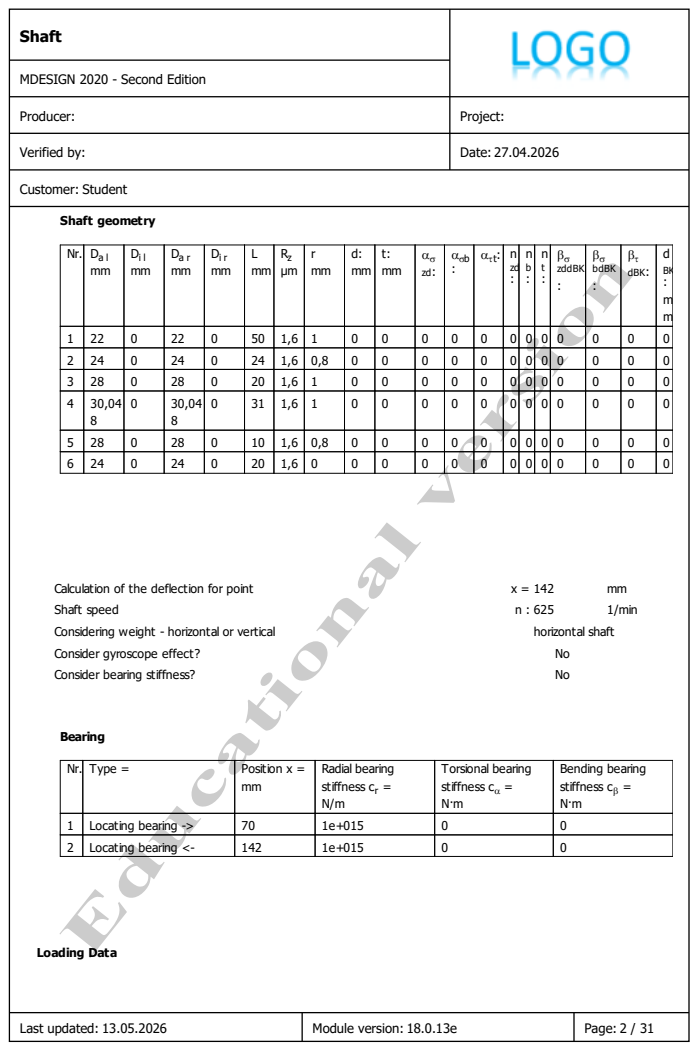
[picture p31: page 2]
Producer:; Project:; Verified by:; Date: 27.04.2026; Customer: Student; Last updated: 13.05.2026; Module version: 18.0.13e; Page: 2 / 31; Shaft geometry; Calculation of the deflection for point; Shaft speed; 1/min; Considering weight - horizontal or vertical; horizontal shaft; Consider gyroscope effect?; Consider bearing stiffness?; Bearing; Loading Data

MDESIGN 2020 - Second Edition

Nr. | Da l mm | Di l mm | Da r mm | Di r mm | L mm | Rz µm | r mm | d: mm | t: mm |  zd: | b : | t : | n zd : | n b : | n t : |  zddBK : |  bdBK : |  dBK: | d BK : m m

1 | 22 | 0 | 22 | 0 | 50 | 1,6 | 1 | 0 | 0 | 0 | 0 | 0 | 0 | 0 | 0 | 0 | 0 | 0 | 0
2 | 24 | 0 | 24 | 0 | 24 | 1,6 | 0,8 | 0 | 0 | 0 | 0 | 0 | 0 | 0 | 0 | 0 | 0 | 0 | 0
3 | 28 | 0 | 28 | 0 | 20 | 1,6 | 1 | 0 | 0 | 0 | 0 | 0 | 0 | 0 | 0 | 0 | 0 | 0 | 0
4 | 30,04 8 | 0 | 30,04 8 | 0 | 31 | 1,6 | 1 | 0 | 0 | 0 | 0 | 0 | 0 | 0 | 0 | 0 | 0 | 0 | 0

5 | 28 | 0 | 28 | 0 | 10 | 1,6 | 0,8 | 0 | 0 | 0 | 0 | 0 | 0 | 0 | 0 | 0 | 0 | 0 | 0
6 | 24 | 0 | 24 | 0 | 20 | 1,6 | 0 | 0 | 0 | 0 | 0 | 0 | 0 | 0 | 0 | 0 | 0 | 0 | 0

Nr. | Type = | Position x = mm | Radial bearing stiffness cr = N/m | Torsional bearing stiffness c = N·m | Bending bearing stiffness c = N·m

1 | Locating bearing -> | 70 | 1e+015 | 0 | 0
2 | Locating bearing <- | 142 | 1e+015 | 0 | 0

MDESIGN 2020 - Second Edition

Axial forces Fax

Nr. | Position x = mm | Amount = N | Radius = mm | Angle  = °

Radial forces Fr

Nr. | Position x = mm | Amount = N | Angle  = °

1 | 20 | -1213,9421 | 270
2 | 109,5 | -1213,9421 | 90
3 | 109,5 | -2785 | 180

Nr. | Position x = mm | Torsion moments Mt : N·mm | Power P: kW | Transition part =

1 | 20 | 55704 | 0 | drive
2 | 109,5 | 55704 | 0 | takeoff

Specifications about the load/loadings

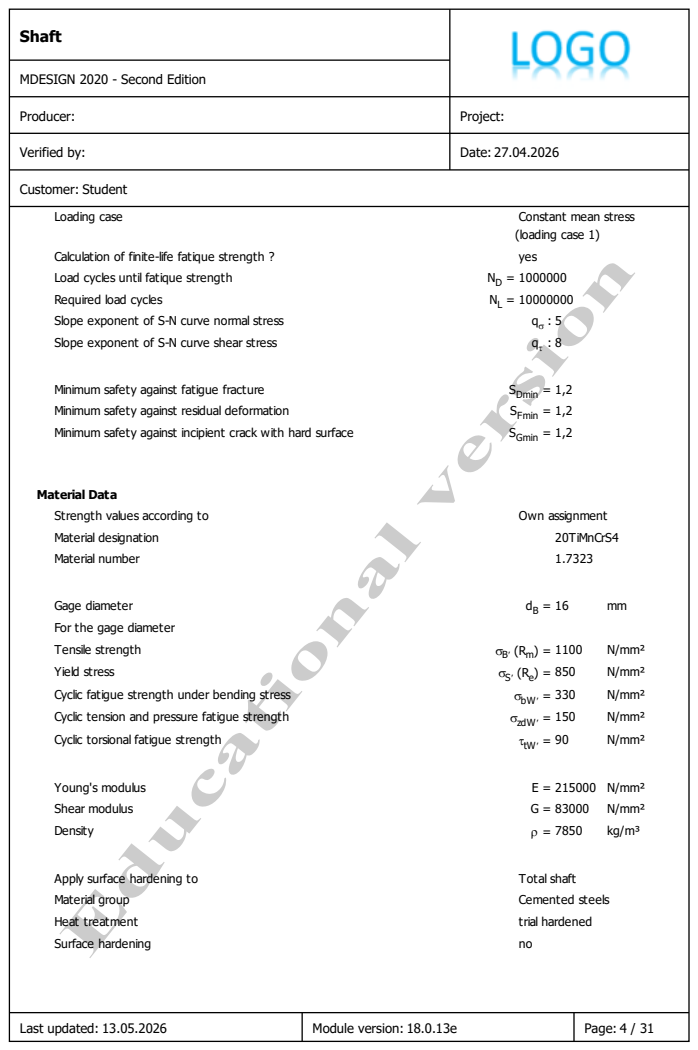
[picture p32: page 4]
Producer:; Project:; Verified by:; Date: 27.04.2026; Customer: Student; Last updated: 13.05.2026; Module version: 18.0.13e; Page: 4 / 31; Loading case; Constant mean stress; (loading case 1); Calculation of finite-life fatique strength ?; yes; Load cycles until fatique strength; Required load cycles; Slope exponent of S-N curve normal stress; Slope exponent of S-N curve shear stress; Minimum safety against fatigue fracture; SDmin = 1,2; Minimum safety against residual deformation; SFmin = 1,2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

MDESIGN 2020 - Second Edition

For the gage diameter
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

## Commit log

2026-08-19 Proiect Organe de Masini: reductor cilindric cu o treapta (RCil H)
    Documentatia completa a proiectului de an: memoriu tehnic, modelele CATIA V5
    (ansamblu, subansamble, piese, desene de ansamblu si de executie), raportul de
    verificare a arborelui de intrare in MDESIGN si tabelele de componenta.
    Tema: Pi = 17,5 kW, ni = 3000 rot/min, iR = 3, Lh = 12000 ore, plan orizontal
    al axelor, z1 = 19. Angrenaj cilindric cu dantura inclinata (beta = 14 grade),
    mn = 2 mm, aw = 80 mm, roti din 20TiMnCr12 cementat.
    [Ansamblu H.CATProduct, CATPart.10.1.1 Rulment radial cu bile de iesire.CATPart, CATPart.10.1.1 Rulment radial cu bile intrare.CATPart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]
2026-08-25 docs: capturi ale modelelor si desenelor in README
    Adaugate in docs/img/ si inserate in ambele versiuni ale README-ului:
    - ansamblul general al reductorului, ca imagine principala
    - angrenajul cilindric in functionare, la capitolul 3
    - subansamblurile celor doi arbori, alaturate, la capitolul 4
    - desenul de ansamblu si desenul de executie al arborelui de iesire,
    la sectiunea Desene
    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
2026-08-25 docs: latimi de afisare potrivite rezolutiei native a capturilor
